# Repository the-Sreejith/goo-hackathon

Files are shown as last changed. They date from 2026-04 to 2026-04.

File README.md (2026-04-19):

# DummE

A small robotic arm on a rotating chassis. Sees its surroundings, understands a natural-language command **in any of 147 languages**, and executes it — all running on-device on a Raspberry Pi 5 using **Gemma 3n E2B**.

> User: *"pick up the red block and put it in the blue cup"* · *"लाल ब्लॉक उठाओ"* · *"أحضر المكعب الأحمر"*
> DummE: sweeps with the camera, finds red, picks it, rotates to blue, drops it in, goes home.

Zero cloud, zero latency, zero privacy compromise — with first-language access built in.

We prototyped the frame in cardboard (it was fragile; see `docs/submission.md` §6). Printable SG90-arm parts now live under `3d-models/` for a sturdier rebuild on the same electronics + software stack.

## Quickstart (MacBook dev)

```bash
git clone https://github.com/the-Sreejith/goo-hackathon
cd goo-hackathon
python3.13 -m venv .venv
source .venv/bin/activate
pip install -r requirements.txt
pip install -e ".[dev]"        # ruff, black, pytest, pytest-cov, httpx
cp .env.example .env

# Smoke test — canonical "pick red, put blue" end-to-end with mocks
python -m scripts.demo_run

# Run the web UI
DUMME_MOCK_HARDWARE=true uvicorn dumme.app:app --reload
# Open http://127.0.0.1:8000
```

Pi-only deps (`picamera2`, `adafruit-circuitpython-pca9685`, `piper-tts`, `vosk`) skip on macOS/x86_64 via platform markers. `DUMME_MOCK_HARDWARE=auto` detects the platform; force with `true`/`false`.

## Pi deployment

Follow [`docs/pi_setup.md`](./docs/pi_setup.md) top-to-bottom for OS flash, WiFi, I2C/SPI, llama.cpp build, and Gemma download. Then from the Mac:

```bash
# Sync code to the Pi (faster than git-on-Pi setup for a hackathon).
rsync -az --exclude '.venv' --exclude '.git' --exclude 'models/*.gguf' \
      --exclude '__pycache__' --exclude '.env' --exclude 'pi-passwords.txt' \
      ./ dumme@dumme.local:/home/dumme/dumme/
```

Install + start the systemd services once:

```bash
ssh dumme@dumme.local '
  sudo cp ~/dumme/systemd/dumme-llama.service /etc/systemd/system/
  sudo cp ~/dumme/systemd/dumme-app.service   /etc/systemd/system/
  sudo systemctl daemon-reload
  sudo systemctl enable --now dumme-llama.service dumme-app.service
'
```

UI lands on `http://dumme.local:8000`, LLM on `http://dumme.local:8080`.

## Voice commands (on-device STT)

DummE can take spoken commands instead of typed ones, transcribed offline by [Vosk](https://alphacephei.com/vosk/) — same privacy guarantees as the rest of the stack.

**Setup:**

```bash
pip install -r requirements.txt
# macOS dev: brew install portaudio
# Pi:        sudo apt install -y libportaudio2

# Download the small English model (~40 MB) into ./models/
curl -LO https://alphacephei.com/vosk/models/vosk-model-small-en-us-0.15.zip
unzip vosk-model-small-en-us-0.15.zip -d models/
mv models/vosk-model-small-en-us-0.15 models/vosk-model-small-en-us
```

Override the default model location with `DUMME_VOSK_MODEL=/path/to/model`.

**Use it:** click the 🎤 Speak button in the browser UI and talk for up to 5 seconds — the transcript populates the input and is sent through the same LLM → orchestrator pipeline as a typed command.

**API:** `POST /listen {"max_seconds": 5.0}` → `{"ok": bool, "message": str, "transcript": str}`.

**Mock mode** (no mic, no model — useful on the dev MacBook):

```bash
DUMME_MOCK_HARDWARE=true DUMME_MOCK_UTTERANCE="pick up the red block" \
    uvicorn dumme.app:app --reload
```

## Tests

```bash
make test            # unit + integration (default — hermetic, ~1 s)
make eval            # live LLM utterance eval (needs llama-server)
make smoke           # scripts/preflight.sh — run on the Pi before demo
make coverage        # pytest --cov with 80% floor
pytest -m hardware   # on the Pi only
```

See [`docs/testing.md`](./docs/testing.md) for the full tier breakdown and eval-report artifact format.

## Docs

| Topic | File |
|---|---|
| Hackathon brief + inventory | [`docs/starting_point.md`](./docs/starting_point.md) |
| Day-of build plan | [`docs/plan.md`](./docs/plan.md) |
| Pi setup (OS, WiFi, llama.cpp, Gemma) | [`docs/pi_setup.md`](./docs/pi_setup.md) |
| Module map + request trace | [`docs/architecture.md`](./docs/architecture.md) |
| GPIO / power / servo wiring | [`docs/wiring.md`](./docs/wiring.md) |
| Test tiers + eval report + CI | [`docs/testing.md`](./docs/testing.md) |
| Demo runbook (pre-flight + 90 s pitch) | [`docs/demo_script.md`](./docs/demo_script.md) |

Index: [`docs/README.md`](./docs/README.md).

## Project layout

```
dumme/          FastAPI app + modules (motion, vision, llm, calibration, io, utils)
config/         YAML configs + Gemma prompt template
static/         Browser UI (HTML + JS + CSS)
scripts/        Hardware smoke tests + preflight.sh + calibration + demo run
tests/          unit + integration + eval + hardware tiers
systemd/        dumme-llama.service + dumme-app.service
docs/           All setup / architecture / testing / demo / submission docs
models/         Gitignored .gguf files (Gemma weights, ~2.8 GB)
3d-models/      Printable SG90 arm + gripper parts (STL / 3MF / Fusion360)
.github/        CI workflow (ruff + black + pytest + coverage upload)
```

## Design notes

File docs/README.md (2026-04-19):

# DummE Docs

One entry per topic. Read `plan.md` and `pi_setup.md` first — every other
doc assumes you've done those.

## Start here

- [starting_point.md](./starting_point.md) — hackathon brief, inventory, prize criteria, final project pitch
- [plan.md](./plan.md) — day-of build plan: MVP slice, roles, schedule, cut list
- [pi_setup.md](./pi_setup.md) — shopping list, headless Pi flash, WiFi, llama.cpp build, Gemma download, systemd services

## Reference (during the build)

- [architecture.md](./architecture.md) — module map, request trace, hardware–software contract
- [wiring.md](./wiring.md) — GPIO pinout, power rails, kill switch, camera, servo channel map
- [testing.md](./testing.md) — test tiers, markers, eval harness, preflight script, coverage gate
- [demo_script.md](./demo_script.md) — pre-demo checklist, 90-second pitch, on-stage recovery
- [submission.md](./submission.md) — hackathon submission write-up (copy-paste into Google Docs)

## Hardware / code map

| Where | What |
|---|---|
| `dumme/app.py` | FastAPI entrypoint, `Services` container, lifespan |
| `dumme/orchestrator.py` | Command → action pipeline (the only module that knows the shape) |
| `dumme/llm/` | Gemma client + JSON-schema-constrained parser |
| `dumme/vision/` | OpenCV USB-camera capture + HSV blob detector |
| `dumme/motion/` | PCA9685 driver + Motion primitives + Safety clamps |
| `dumme/calibration/` | Pixel → (r, θ) affine regression |
| `dumme/io/` | Piper TTS + Vosk STT |
| `config/` | YAML configs + Gemma prompt template |
| `scripts/` | Hardware smoke utilities + `preflight.sh` + prompt eval |
| `tests/` | Unit + integration + eval + hardware tiers |
| `systemd/` | `dumme-llama.service`, `dumme-app.service` |
| `3d-models/` | Printable SG90 arm + gripper parts (STL / 3MF / Fusion 360) |

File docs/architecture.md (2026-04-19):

# DummE — Architecture

```
┌────────────────────────────────────────────────────────────┐
│                      Browser (any device)                   │
│              Text input + live camera MJPEG                 │
└────────────────────────────┬───────────────────────────────┘
                             │ HTTP
┌────────────────────────────▼───────────────────────────────┐
│                   FastAPI app (dumme/app.py)                │
│  POST /command   GET /stream   GET /status   POST /estop    │
└──┬────────────────┬────────────────┬───────────────────────┘
   │                │                │
┌──▼────────┐  ┌────▼─────┐   ┌──────▼──────────┐
│  llm/     │  │ vision/  │   │  orchestrator   │
│ Gemma 3n  │  │ cv2 UVC  │   │  Sweep → detect │
│ JSON-only │  │ + HSV    │   │  → pick → place │
└───────────┘  └──────────┘   └──────┬──────────┘
                                     │
                              ┌──────▼──────┐
                              │  motion/    │
                              │  PCA9685 +  │
                              │  primitives │
                              └──────┬──────┘
                                     │ I2C
                              ┌──────▼──────┐
                              │  PCA9685    │
                              │  → 5 servos │
                              └─────────────┘
```

## Module Responsibilities

### `dumme.app` — FastAPI entrypoint
Builds the `Services` container at startup (reads `config/*.yaml`), wires routes, serves `static/`. Every request handler delegates into `Orchestrator`, `LLM`, `Motion`, or `Camera` — no business logic lives in route handlers.

### `dumme.orchestrator` — The Command → Action loop
The only module that knows the pipeline shape. `execute(cmd)` dispatches `home` / `pick_and_place` / `unknown`. `sweep_and_detect(color)` iterates the turntable in 15° steps, calling `vision.find(color)` at each stop until a hit (or the full sweep completes).

### `dumme.motion/` — Hardware actuation
- `driver.PCA9685Driver` — microsecond-level PWM writes, lazy-imports `adafruit_pca9685` so this module loads on a MacBook.
- `primitives.Motion` — verbs the orchestrator calls (`home`, `pick`, `place`, `release_all`, `estop`). Every write goes through `Safety.clamp` and honours `Safety.estop`.
- `safety.Safety` — joint-limit clamping + thread-safe `EstopFlag`.

### `dumme.vision/` — Perception
- `camera.Camera` — `cv2.VideoCapture(0, cv2.CAP_V4L2)` wrapper for USB UVC webcams. One-shot + MJPEG generator. Falls back to solid-colour frames in mock mode.
- `detector.Vision` — HSV masking + morphology + contour selection. Returns `Detection(color, pixel_xy, area_px)` or `None`. Red hue wraps, so the config OR's two ranges together.

### `dumme.llm/` — Utterance → Command
- `client.LlamaClient` — HTTP client for local llama.cpp server on port 8080.
- `parser.LLM` — fills the prompt template, extracts JSON, validates, retries once. Falls back to `Command("unknown", ...)`.
- `schema` — `Command`, `ExecutionResult` dataclasses + `ok()`/`fail()` helpers.
- **Multilingual**: Gemma 3n covers 147 languages. The prompt template + JSON schema are language-agnostic — the same `Command("pick_and_place", "red", "blue")` comes out whether the user said "pick the red one" or "लाल ब्लॉक उठाओ". No per-locale build.

### `dumme.calibration/` — Pixel → polar (r, θ)
Affine regression fit from 5+ hand-captured samples. Used by the orchestrator to turn a detected pixel into a motion target.

### `dumme.io/` — Speech I/O
- `tts.TTS` — Piper wrapper for spoken replies.
- `mic.Mic` — Vosk STT, stretch only.

### `dumme.utils/` — Shared infrastructure
- `config.load_yaml` — reads `config/*.yaml`, resolves `DUMME_CONFIG_DIR` override.
- `logging.get_logger` — structured logging, respects `LOG_LEVEL`.

## Request Trace: `POST /command`

```
POST /command {"utterance": "pick red, drop blue"}
  → app.post_command
  → services.llm.parse(utterance)                 # HTTP → llama-server → JSON → Command
  → services.orchestrator.execute(cmd)
    → motion.base_rotate / turntable_rotate       # sweep
    → vision.find(target_color) ... (repeat)
    → calibration.pixel_to_polar(...)
    → motion.pick(r, θ)
    → (same for destination)
    → motion.place(r, θ); motion.home()
  → return ExecutionResult → JSON
```

## Hardware-Software Contract

| Concern | Boundary |
|---|---|
| PCA9685 I2C address | `0x40` (default) — `config/servos.yaml` is source of truth for channels |
| Servo pulse range | `min_us` / `max_us` per joint in `config/servos.yaml` |
| Joint soft limits | `joint_limits` in `config/servos.yaml` — enforced by `Safety.clamp` |
| Gemma backend | `http://127.0.0.1:8080/completion` — override via `LLAMA_URL` env. Current weights: `gemma-3n-E2B-it-Q4_K_M.gguf` (~2.8 GB). |
| Camera device | `/dev/video0` via OpenCV V4L2 (USB UVC). `picamera2` is supported if you wire a CSI ribbon and swap `Camera._open`. |

## Testing Strategy

See [testing.md](./testing.md) for the full breakdown. In short:

- **Unit** (`@pytest.mark.unit`, default) — hermetic logic: JSON extraction, regression math, safety clamps, motion pulse math, vision HSV, orchestrator dispatch with fakes, LLM client with mocked `requests`.
- **Integration** (`@pytest.mark.integration`, default) — FastAPI `TestClient` with a stubbed LLM.
- **Eval** (`@pytest.mark.eval`, opt-in) — live-LLM accuracy suite parametrized over 20 canonical utterances in `scripts/prompt_test.py::CASES`.
- **Hardware** (`@pytest.mark.hardware`, opt-in) — Pi-only: I2C ack at 0x40, camera frame variance, llama-server roundtrip.
- **Preflight** (`scripts/preflight.sh`) — 5-minute shell sanity check before demo.

The default `pytest` / `make test` run covers unit+integration; `make eval`, `pytest -m hardware`, and `make smoke` are the opt-in tiers.

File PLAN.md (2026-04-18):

# DummE — Physical AI Hackathon 2026 Build Plan

> **Goal**: A cardboard robotic arm on a rotating chassis that sees its surroundings, understands a natural-language command, and executes it — all running on-device on a Raspberry Pi 5 using Gemma.
>
> **Team**: 3 people. **Time**: 1 day. **Track**: Open Challenge / Accessibility (indoor assistance aide).

---

## 1. The MVP Demo

**Storyboard (90 seconds, the whole pitch):**

1. User opens the web UI and types or speaks: *"Pick up the red block and put it in the blue cup."*
2. DummE's chassis **rotates slowly**, sweeping the workspace with the camera.
3. When the red block enters the frame, DummE **stops** and says (TTS): *"Found the red block."*
4. The arm **picks** the block, the chassis **rotates** toward the blue cup, and the arm **drops** it in.
5. DummE returns to home pose and says: *"Task complete."*

That is the entire demo. Every feature not on this list is cut.

---

## 2. Hardware

### 2.1 BOM (from provided inventory)

| Part | Role | Qty |
|---|---|---|
| Raspberry Pi 5 (4GB) | Brain — vision, LLM, orchestration | 1 |
| Pi Camera Module | Perception | 1 |
| PCA9685 16-ch PWM Driver | Drives all servos over I2C | 1 |
| SG90 Micro Servo | Arm joints: base-rotate, shoulder, elbow, gripper | 4 |
| **MG90S Micro Servo** | **Chassis turntable** (holds the whole arm) | 1 |
| HC-SR04 Ultrasonic | Workspace safety stop (optional) | 1 |
| 5V/5A USB-C PSU | Pi power | 1 |
| 5–6V/3A battery or PSU | Servo power (separate rail) | 1 |

**Not used** (stay on the table for the hero photo): ESP32, Arduino Uno, remaining MG995s, GPS, DHT, BME, HX711, MPU6050, IR sensor.

### 2.2 Power Rules (critical)

- **Pi on its own USB-C 5V/5A.**
- **Servos on a separate 5–6V/3A rail.** Never power servos from the Pi's 5V pin — they'll brown out the CPU.
- **Common ground only** between the two rails.
- **Physical kill switch** (toggle or inline button) on the servo V+ line. You will need it.

### 2.3 Mechanical

**Arm (4-DOF, SG90s):**

| Joint | Servo | Range |
|---|---|---|
| J1 — base rotate | SG90 #1 | 0–180° |
| J2 — shoulder | SG90 #2 | 30–150° |
| J3 — elbow | SG90 #3 | 20–160° |
| J4 — gripper | SG90 #4 | open/close |

**Chassis turntable:** MG90S mounted below two cardboard discs. A skewer or dowel pin runs through the center of both discs as the rotation axis. A plastic lid or 3D-printed washer sits between them for low friction. The arm's base plate is glued to the top disc.

### 2.4 Cardboard Assembly Rules

SG90s are forgiving on cardboard (low torque), but these rules still matter:

- **Double-layer corrugated**, grain directions crossed, hot-glued.
- **Bamboo skewers or chopsticks** as internal bracing along every arm segment.
- **Servo horns**: sandwich the horn between the cardboard and a second small cardboard plate + washer. Screws pull through a single layer.
- **Keep arm segments short** (<15 cm each). Long segments amplify torque and cause sag.
- **Heavy base**: tape the chassis base to a book, a hardcover, or a box weighted with anything dense. A top-heavy arm will tip during a swing.
- **Cable routing**: run servo wires through the turntable's center pin area, leave slack so rotation doesn't yank them.

### 2.5 Payload Budget

SG90 torque ≈ 1.8 kg·cm. With a 10 cm forearm, payload at the gripper tip is roughly **100–150 g max**. Safe target objects:

- Ping-pong ball
- Foam cube (3 cm)
- Bottle cap
- Small plastic block

Avoid anything heavier than a matchbox.

---

## 3. Software Architecture

```
┌────────────────────────────────────────────────────────────┐
│                      Browser (any device)                   │
│              Text input + live camera MJPEG                 │
└────────────────────────────┬───────────────────────────────┘
                             │ HTTP
┌────────────────────────────▼───────────────────────────────┐
│                   FastAPI app (app.py)                      │
│  POST /command   GET /stream   GET /status   POST /estop   │
└──┬────────────────┬────────────────┬───────────────────────┘
   │                │                │
┌──▼────────┐  ┌────▼─────┐   ┌──────▼──────────┐
│  llm.py   │  │ vision.py│   │  orchestrator.py│
│ Gemma +   │  │ picamera2│   │  Sweep → detect │
│ JSON-only │  │ + HSV    │   │  → pick → place │
└───────────┘  └──────────┘   └──────┬──────────┘
                                     │
                              ┌──────▼──────┐
                              │  motion.py  │
                              │  PCA9685 +  │
                              │  primitives │
                              └──────┬──────┘
                                     │ I2C
                              ┌──────▼──────┐
                              │  PCA9685    │
                              │  → 5 servos │
                              └─────────────┘
```

### 3.1 Repo Layout

```
dumme/
├── app.py                  # FastAPI entrypoint, serves UI
├── config.yaml             # servo limits, HSV ranges, calibration
├── dumme/
│   ├── __init__.py
│   ├── motion.py           # PCA9685 driver, motion primitives
│   ├── vision.py           # picamera2 + HSV detection
│   ├── llm.py              # Gemma wrapper, JSON-strict prompt
│   ├── calibration.py      # pixel → (r, θ) map
│   └── orchestrator.py     # main command loop
├── static/
│   └── index.html          # single-file browser UI
├── models/
│   └── gemma-4-e2b-it-Q4_K_M.gguf   # primary model (fallback: gemma-3n-E2B-Q4)
├── scripts/
│   ├── servo_sweep.py      # sanity-check each servo
│   ├── calibrate.py        # interactive calibration ritual
│   └── test_pipeline.py    # scripted end-to-end demo
├── requirements.txt
└── README.md
```

### 3.2 Key Interfaces

**`motion.py`**
```python
class Motion:
    def home(self) -> None: ...
    def base_rotate(self, angle_deg: float) -> None: ...
    def pick(self, r_mm: float, theta_deg: float) -> None: ...
    def place(self, r_mm: float, theta_deg: float) -> None: ...
    def release_all(self) -> None: ...    # zero PWM, stops jitter
    def estop(self) -> None: ...          # freeze + cut power flag
```

**`vision.py`**
```python
@dataclass(frozen=True)
class Detection:
    color: str
    pixel_xy: tuple[int, int]
    area_px: int

class Vision:
    def frame(self) -> np.ndarray: ...
    def find(self, color: str) -> Detection | None: ...
```

**`llm.py`**
```python
@dataclass(frozen=True)
class Command:
    action: str                  # "pick_and_place" | "home" | "unknown"
    target_color: str | None
    dest_color: str | None

class LLM:
    def parse(self, utterance: str) -> Command: ...
```

**`orchestrator.py`**
```python
class Orchestrator:
    def execute(self, cmd: Command) -> ExecutionResult: ...
```

### 3.3 Gemma Model Choice

**Primary: Gemma 4 E2B (Q4_K_M GGUF)** — released April 2, 2026, first-party fit for the prize criteria.

| Aspect | Value |
|---|---|
| Model file | `gemma-4-e2b-it-Q4_K_M.gguf` (~1.6 GB) |
| Effective params | ~2.3B |
| Multimodal | Text + image + video in (we use text only) |
| Throughput on 4GB Pi 5 | ~2–6 tokens/sec (enough for ~30-token JSON) |
| Context cap | `--ctx-size 2048` (native 128K is too much KV cache for 4GB) |

**Fallback: Gemma 3n E2B Q4** — swap in if Gemma 4 E2B misbehaves under time pressure.

**Do NOT use on this Pi**: Gemma 4 E4B (~3GB, no RAM headroom), 26B MoE, 31B Dense.

**llama.cpp launch command**:
```bash
llama-server \
  -m models/gemma-4-e2b-it-Q4_K_M.gguf \
  --ctx-size 2048 \
  --n-predict 128 \
  --threads 4 \
  --host 127.0.0.1 --port 8080
```

### 3.4 Gemma Prompt (JSON-strict)

System prompt enforces the schema. Few-shot examples cover common phrasings. Retry once if output isn't valid JSON.

```
You are DummE's command parser. Convert the user's request to JSON ONLY.
Do not add commentary. Do not use markdown fences.

Schema:
{
  "action": "pick_and_place" | "home" | "unknown",
  "target_color": "red" | "blue" | "green" | null,
  "dest_color":   "red" | "blue" | "green" | null
}

Examples:
User: "pick up the red block and put it in the blue cup"
{"action":"pick_and_place","target_color":"red","dest_color":"blue"}

User: "grab the green one and drop it in red"
{"action":"pick_and_place","target_color":"green","dest_color":"red"}

User: "go home"
{"action":"home","target_color":null,"dest_color":null}

User: "dance for me"
{"action":"unknown","target_color":null,"dest_color":null}
```

### 3.5 Main Loop (pseudocode)

```python
def execute(cmd: Command) -> ExecutionResult:
    if cmd.action == "home":
        motion.home(); return ok()
    if cmd.action == "unknown":
        return fail("I didn't understand that.")

    # Sweep to find target
    target_hit = sweep_and_detect(cmd.target_color)
    if not target_hit:
        return fail(f"I can't see the {cmd.target_color} object.")

    # Pick
    r, theta = calibration.pixel_to_polar(target_hit.pixel_xy, motion.base_angle)
    motion.pick(r, theta)

    # Find destination
    dest_hit = sweep_and_detect(cmd.dest_color)
    if not dest_hit:
        motion.home(); return fail(f"I can't see the {cmd.dest_color} destination.")

    # Place
    r2, theta2 = calibration.pixel_to_polar(dest_hit.pixel_xy, motion.base_angle)
    motion.place(r2, theta2)
    motion.home()
    return ok()
```

---

## 4. Team Split

| Person | Track | Owns |
|---|---|---|
| **P1** | Hardware | Cardboard cut + assembly, servo mounting, PCA9685 wiring, power rails, kill switch |
| **P2** | Perception + LLM | `vision.py`, `llm.py`, Gemma setup, browser UI, live camera feed |
| **P3** | Motion + Integration | `motion.py`, `calibration.py`, `orchestrator.py`, `app.py`, demo script |

**Golden rule**: everyone commits a working stub to `main` in the first hour. No one waits on anyone.

---

## 5. Phased Execution

### Phase A — End-to-end skeleton (parallel, ~1 hour)

All three people land code on `main` **before any real hardware works**.

**P1 (Hardware)**
- Cut cardboard from the blueprint.
- Dry-fit arm + turntable (no glue yet).
- Label every servo wire (J1/J2/J3/J4/TURN).
- Solder power rail.

**P2 (Perception + LLM)**
- `vision.find()` returns a hardcoded fake `Detection` for any color.
- `llm.parse()` returns a hardcoded `Command` for one test string.
- Minimal HTML page: text box + Submit button + `<img src="/stream">`.

**P3 (Motion + Integration)**
- `motion.*` methods `print()` what they would do, no hardware calls.
- FastAPI app with `/command`, `/stream`, `/status`, `/estop`.
- `orchestrator.execute()` glues the three stubs.

**Exit gate**: typing "pick red, put blue" in the browser prints the full pipeline trace to the console. Nothing real works yet — that's fine.

### Phase B — Swap stubs for reality (parallel, ~3 hours)

**P1 (Hardware)**
- Final glue-up of arm and turntable.
- Mount Pi, camera, and PCA9685 on the chassis.
- Weight the base. Confirm turntable holds the arm without creep.
- Join P3 during calibration (hour ~4).

**P2 (Perception + LLM)**
1. `picamera2` live capture → Flask MJPEG stream at `/stream`.
2. HSV color masks for red, blue, green. Tune under the actual demo lighting.
3. `Vision.find(color)` returns the largest contour's centroid + area. Reject detections with area < threshold.
4. Install `llama.cpp` on Pi. Download **Gemma 4 E2B Q4_K_M GGUF** (~1.6 GB) to `models/`. Keep Gemma 3n E2B Q4 as a pre-downloaded fallback on disk.
5. Launch `llama-server` with `--ctx-size 2048 --threads 4`. Wire `LLM.parse()` to hit it over HTTP with the JSON-strict prompt.
6. Test **20+ phrasings**. Add few-shot examples until ≥95% parse correctly.
7. Add `piper` TTS for spoken replies.

**P3 (Motion + Integration)**
1. `Motion` class wraps `adafruit_pca9685`. Every servo has `min_us`, `max_us`, `home_deg` in `config.yaml`.
2. `scripts/servo_sweep.py` — sanity-check each servo individually.
3. **Calibration ritual** (run WITH the real arm, not simulated):
   - Place a block at 5 known `(x, y)` positions on the workspace.
   - For each: manually jog the arm to a good pick pose, record `(base_angle, shoulder, elbow)` and the pixel location of the block in the camera frame at turntable angle 0.
   - Fit a regression: `(pixel_x, pixel_y) → (shoulder, elbow)`. Linear or affine is fine.
   - Turntable rotation adds a constant offset: `absolute_theta = pixel_theta + turntable_angle`.
4. Primitives: `home()`, `base_rotate()`, `pick(r, theta)`, `place(r, theta)`, `release_all()`, `estop()`.
5. `sweep_and_detect(color)` — rotate turntable in 15° steps from -60° to +60°, capture frame at each stop, return first hit.

### Phase C — Integration + demo hardening (~2 hours)

- Run the full loop **10 times**. Each failure → a guard rail or a demo-script workaround.
- Common fixes you'll add:
  - Servo jitter at rest → `release_all()` after every primitive.
  - Block outside reach → polite TTS error + return to home.
  - Gripper slips the ball → slow down the lift; add a foam pad on the gripper tips.
  - Turntable slips → bigger servo horn contact area, more glue.
- **Record the demo video now.** Do not leave it for the last 15 minutes.
- Write the README with architecture diagram, Gemma callout, wiring photos.

### Phase D — Stretch goals (only if green by hour 7)

- Voice input via Vosk tiny (offline STT).
- A third color / object class.
- OLED status display over I2C.
- Ultrasonic e-stop: if HC-SR04 reads <20cm (human hand in workspace), freeze the arm.
- `sweep_and_detect` early-stop animation (rotate toward the target smoothly).

---

## 6. Hard Cuts (confirmed)

- ❌ 6-DOF arm — 4 is enough.
- ❌ Real inverse kinematics — regression from calibration points suffices.
- ❌ Wrist pitch/roll — gripper approaches vertically.
- ❌ Wheeled mobility — the chassis rotates but doesn't drive.
- ❌ Depth camera / stereo — workspace is a flat table at a known height.
- ❌ ESP32 / Arduino — Pi drives PCA9685 directly over I2C.
- ❌ Cloud LLM — Gemma on-device is the prize story.
- ❌ GPS, DHT, BME, HX711, MPU, IR — out of scope for the MVP.

---

## 7. Risk Register

| Risk | Likelihood | Mitigation |
|---|---|---|
| Arm tips forward when reaching | High | Heavy base (tape book/board under chassis) |
| SG90 jitter at rest | High | `release_all()` (PWM=0) after each motion |
| SG90s overheat during calibration | Medium | Short bursts; arm rests on cardboard support in home pose |
| Gemma returns malformed JSON | Medium | Strict schema prompt + 1-retry with reminder; regex extract `{...}` |
| Gemma 4 E2B hits RAM limit on 4GB Pi | Medium | Fall back to Gemma 3n E2B Q4 (pre-downloaded); drop `--ctx-size` to 1024 |
| Gemma token throughput too slow | Medium | Show "Thinking…" in UI; keep prompt short; cap `--n-predict 128` |
| HSV mask misses block under shadow | High | White sheet as workspace + desk lamp for even lighting |
| Cable pulled during base rotation | Medium | Route through turntable center; leave slack loop |
| Turntable slips under load | Medium | MG90S horn glued AND screwed; short arm segments |
| Pi CPU overload (vision + LLM) | Medium | Detect and LLM don't run concurrently; Gemma Q4 quantization |
| Gripper drops the ball | High | Foam pads on gripper tips; slow lift speed |
| Demo ambient light changes | Medium | Recalibrate HSV just before demo; add a lamp |

---

## 8. Prize Criteria Fit

- **Gemma 4**: we run **Gemma 4 E2B** (released April 2, 2026) **on-device** via `llama.cpp` on a 4GB Pi 5. First-party alignment with the prize's Gemma 4 preference — no cloud inference, no API calls, structured JSON output driving real-world actuation.
- **GCP ($5 budget)**: use Vertex AI only as an optional fallback for commands Gemma 4 can't parse, and cache aggressively. An on-device-only story is simpler and probably more compelling — lean on "zero cloud, zero latency, zero privacy compromise" as the narrative.
- **Physical AI**: camera + servos + cardboard form factor + real-world pick-and-place.
- **Track fit** (Accessibility or Open): voice/text command → physical action maps directly to "empowering people with disabilities" or "open-ended AI + hardware".

---

## 9. Pre-flight Checklist

**Hardware, OS, and model setup are documented in [`PI_SETUP.md`](./PI_SETUP.md).** Complete every step (including the verification checklist in §9 of that doc) **before** hack day starts.

**Project-specific readiness** (additional to `PI_SETUP.md`):
- [ ] Repo scaffold (`app.py`, `motion.py`, `vision.py`, `llm.py`, `config.yaml`, `scripts/`) pushed to GitHub.
- [ ] Cardboard blueprints printed.
- [ ] Props on hand: cardboard sheets, hot glue, skewers, foam cubes, ping-pong ball, coloured cups, desk lamp, white workspace backdrop.
- [ ] 1–2 extra SG90 servos (burnout insurance).
- [ ] Kill switch wired inline on servo V+ and physically tested (multimeter-verified).

---

## 10. One-Page Demo Day Runbook

1. **30 min before**: power up, run `scripts/test_pipeline.py`, recalibrate HSV under demo lighting.
2. **10 min before**: home pose, release servos, close unused apps on the Pi.
3. **Demo**:
   - Show the cardboard arm (authenticity wins hearts).
   - Open the browser UI on a phone or laptop.
   - Type the command. Let Gemma parse (show the JSON on screen).
   - Watch the sweep, pick, place, return home.
   - Final line: *"Everything you saw ran on the Pi. No cloud."*
4. **Backup**: if live run fails, play the pre-recorded video immediately. Do not freeze.

---

**Ready to scaffold the repo?** Once the plan is approved, create the directory tree in §3.1 and commit working stubs so P1/P2/P3 can start in parallel.

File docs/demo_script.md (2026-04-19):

# DummE — Demo Day Runbook

## 30 min before

- [ ] Power up Pi + servo rail, open SSH from all 3 MacBooks.
- [ ] `bash scripts/preflight.sh` — green on all 5 checks. If not, fix now.
- [ ] `python -m scripts.servo_sweep` — each joint rotates through full range, no binding.
- [ ] `python -m scripts.prompt_test` — ≥ 18/20 pass. (Or `pytest -m eval` for the report artifact.)
- [ ] Recalibrate HSV: `python -m scripts.camera_preview` under the demo lighting, tweak `config/vision.yaml`.
- [ ] Confirm systemd services are running: `systemctl status dumme-llama.service dumme-app.service --no-pager`.
- [ ] Run `python -m scripts.demo_run` — result `ok=True`.

## 10 min before

- [ ] Motion to home pose; call `release_all()` so servos aren't jittering on stage.
- [ ] Close unused apps on the Pi (`pgrep -af python` — kill strays).
- [ ] White workspace backdrop laid out, desk lamp on.
- [ ] Target blocks + cups placed within reach envelope.
- [ ] Phone/laptop has `http://dumme.local:8000` open.
- [ ] **Backup video cued up** in case live run fails.

## The Demo (90 seconds)

1. **Introduce the arm** (10s) — "This is DummE. 100% cardboard. 4-DOF arm on a rotating chassis. The Pi 5 you see on the base runs Gemma 3n E2B locally — zero cloud."
2. **Open the UI** (5s) — show the camera feed, say what we're about to ask for.
3. **Type the command** (10s) — "pick up the red block and put it in the blue cup". (Optional wow beat: repeat it in a second language — *"लाल ब्लॉक उठाओ"* or the judge's first language — to show Gemma 3n's 147-language coverage in one device.)
4. **Gemma parses** (5s) — briefly show the returned JSON on screen. Mention: on-device, ~1–3 seconds at ~5 tok/s on CPU.
5. **Arm acts** (45s) — chassis sweeps, finds red, picks, rotates, drops in blue, returns home.
6. **Close the pitch** (15s) — "Everything you saw ran on the Pi. No cloud, no API calls, no network round-trip. That's the Gemma story at the edge."

## If the live run fails

Do not freeze. Say: *"Let me show you the run we recorded this morning — same code, same hardware."* Hit play on the backup video. The pitch continues.

## Common on-stage recovery

| Symptom | Quick fix |
|---|---|
| Arm doesn't move | Check kill switch; POST `/estop/clear`. |
| "I can't see the X object" | Move the block; adjust lamp; re-send. |
| Gripper drops the ball | Add a foam pad (cue in pocket); reduce lift speed in `config/servos.yaml`. |
| Servo jitter when idle | `release_all()` wasn't called — POST `/command {"utterance":"go home"}` then stop. |
| Camera feed black | Ribbon cable reversed. Flip it. (Pre-flight should catch this.) |

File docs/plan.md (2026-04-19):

# DummE — Physical AI Hackathon 2026 Build Plan

> **Goal**: A cardboard robotic arm on a rotating chassis that sees its surroundings, understands a natural-language command, and executes it — all running on-device on a Raspberry Pi 5 using Gemma.
>
> **Team**: 3 people. **Time**: 1 day. **Track**: Open Challenge / Accessibility (indoor assistance aide).

---

## 1. The MVP Demo

**Storyboard (90 seconds, the whole pitch):**

1. User opens the web UI and types or speaks: *"Pick up the red block and put it in the blue cup."*
2. DummE's chassis **rotates slowly**, sweeping the workspace with the camera.
3. When the red block enters the frame, DummE **stops** and says (TTS): *"Found the red block."*
4. The arm **picks** the block, the chassis **rotates** toward the blue cup, and the arm **drops** it in.
5. DummE returns to home pose and says: *"Task complete."*

That is the entire demo. Every feature not on this list is cut.

---

## 2. Hardware

### 2.1 BOM (from provided inventory)

| Part | Role | Qty |
|---|---|---|
| Raspberry Pi 5 (4GB) | Brain — vision, LLM, orchestration | 1 |
| Pi Camera Module | Perception | 1 |
| PCA9685 16-ch PWM Driver | Drives all servos over I2C | 1 |
| SG90 Micro Servo | Arm joints: base-rotate, shoulder, elbow, gripper | 4 |
| **MG90S Micro Servo** | **Chassis turntable** (holds the whole arm) | 1 |
| HC-SR04 Ultrasonic | Workspace safety stop (optional) | 1 |
| 5V/5A USB-C PSU | Pi power | 1 |
| 5–6V/3A battery or PSU | Servo power (separate rail) | 1 |

**Not used** (stay on the table for the hero photo): ESP32, Arduino Uno, remaining MG995s, GPS, DHT, BME, HX711, MPU6050, IR sensor.

### 2.2 Power Rules (critical)

- **Pi on its own USB-C 5V/5A.**
- **Servos on a separate 5–6V/3A rail.** Never power servos from the Pi's 5V pin — they'll brown out the CPU.
- **Common ground only** between the two rails.
- **Physical kill switch** (toggle or inline button) on the servo V+ line. You will need it.

### 2.3 Mechanical

**Arm (4-DOF, SG90s):**

| Joint | Servo | Range |
|---|---|---|
| J1 — base rotate | SG90 #1 | 0–180° |
| J2 — shoulder | SG90 #2 | 30–150° |
| J3 — elbow | SG90 #3 | 20–160° |
| J4 — gripper | SG90 #4 | open/close |

**Chassis turntable:** MG90S mounted below two cardboard discs. A skewer or dowel pin runs through the center of both discs as the rotation axis. A plastic lid or 3D-printed washer sits between them for low friction. The arm's base plate is glued to the top disc.

### 2.4 Cardboard Assembly Rules

SG90s are forgiving on cardboard (low torque), but these rules still matter:

- **Double-layer corrugated**, grain directions crossed, hot-glued.
- **Bamboo skewers or chopsticks** as internal bracing along every arm segment.
- **Servo horns**: sandwich the horn between the cardboard and a second small cardboard plate + washer. Screws pull through a single layer.
- **Keep arm segments short** (<15 cm each). Long segments amplify torque and cause sag.
- **Heavy base**: tape the chassis base to a book, a hardcover, or a box weighted with anything dense. A top-heavy arm will tip during a swing.
- **Cable routing**: run servo wires through the turntable's center pin area, leave slack so rotation doesn't yank them.

### 2.5 Payload Budget

SG90 torque ≈ 1.8 kg·cm. With a 10 cm forearm, payload at the gripper tip is roughly **100–150 g max**. Safe target objects:

- Ping-pong ball
- Foam cube (3 cm)
- Bottle cap
- Small plastic block

Avoid anything heavier than a matchbox.

---

## 3. Software Architecture

```
┌────────────────────────────────────────────────────────────┐
│                      Browser (any device)                   │
│              Text input + live camera MJPEG                 │
└────────────────────────────┬───────────────────────────────┘
                             │ HTTP
┌────────────────────────────▼───────────────────────────────┐
│                   FastAPI app (app.py)                      │
│  POST /command   GET /stream   GET /status   POST /estop   │
└──┬────────────────┬────────────────┬───────────────────────┘
   │                │                │
┌──▼────────┐  ┌────▼─────┐   ┌──────▼──────────┐
│  llm.py   │  │ vision.py│   │  orchestrator.py│
│ Gemma 3n  │  │ cv2 UVC  │   │  Sweep → detect │
│ JSON-only │  │ + HSV    │   │  → pick → place │
└───────────┘  └──────────┘   └──────┬──────────┘
                                     │
                              ┌──────▼──────┐
                              │  motion.py  │
                              │  PCA9685 +  │
                              │  primitives │
                              └──────┬──────┘
                                     │ I2C
                              ┌──────▼──────┐
                              │  PCA9685    │
                              │  → 5 servos │
                              └─────────────┘
```

### 3.1 Repo Layout

```
dumme/
├── app.py                  # FastAPI entrypoint, serves UI
├── config.yaml             # servo limits, HSV ranges, calibration
├── dumme/
│   ├── __init__.py
│   ├── motion.py           # PCA9685 driver, motion primitives
│   ├── vision.py           # OpenCV UVC + HSV detection
│   ├── llm.py              # Gemma wrapper, JSON-strict prompt
│   ├── calibration.py      # pixel → (r, θ) map
│   └── orchestrator.py     # main command loop
├── static/
│   └── index.html          # single-file browser UI
├── models/
│   └── gemma-3n-E2B-it-Q4_K_M.gguf  # active model (~2.8 GB)
├── scripts/
│   ├── servo_sweep.py      # sanity-check each servo
│   ├── calibrate.py        # interactive calibration ritual
│   └── test_pipeline.py    # scripted end-to-end demo
├── requirements.txt
└── README.md
```

### 3.2 Key Interfaces

**`motion.py`**
```python
class Motion:
    def home(self) -> None: ...
    def base_rotate(self, angle_deg: float) -> None: ...
    def pick(self, r_mm: float, theta_deg: float) -> None: ...
    def place(self, r_mm: float, theta_deg: float) -> None: ...
    def release_all(self) -> None: ...    # zero PWM, stops jitter
    def estop(self) -> None: ...          # freeze + cut power flag
```

**`vision.py`**
```python
@dataclass(frozen=True)
class Detection:
    color: str
    pixel_xy: tuple[int, int]
    area_px: int

class Vision:
    def frame(self) -> np.ndarray: ...
    def find(self, color: str) -> Detection | None: ...
```

**`llm.py`**
```python
@dataclass(frozen=True)
class Command:
    action: str                  # "pick_and_place" | "home" | "unknown"
    target_color: str | None
    dest_color: str | None

class LLM:
    def parse(self, utterance: str) -> Command: ...
```

**`orchestrator.py`**
```python
class Orchestrator:
    def execute(self, cmd: Command) -> ExecutionResult: ...
```

### 3.3 Gemma Model Choice

**Active: Gemma 3n E2B (Q4_K_M GGUF)** — edge-optimised, supported by llama.cpp, validated on Pi 5.

| Aspect | Value |
|---|---|
| Model file | `gemma-3n-E2B-it-Q4_K_M.gguf` (~2.8 GB; `unsloth` mirror) |
| Effective params | ~2 B |
| Multimodal | Text-only on our path |
| Throughput on 4GB Pi 5 | ~3–5 tokens/sec (plenty for a ~20-token JSON reply) |
| Context cap | `--ctx-size 2048` (native 128K is too much KV cache for 4GB) |

> The original plan targeted **Gemma 4 E2B** for first-party prize alignment, but that variant isn't available as a published GGUF on Hugging Face at build time. Gemma 3n E2B is the functionally equivalent replacement — same on-device Gemma story, shippable.

**Do NOT use on this Pi**: Gemma 3n E4B (~4 GB, no RAM headroom for app + OS), 26B MoE, 31B Dense.

**llama.cpp launch command** (or use `systemctl start dumme-llama.service`):
```bash
llama-server \
  -m models/gemma-3n-E2B-it-Q4_K_M.gguf \
  --ctx-size 2048 \
  --threads 4 \
  --host 127.0.0.1 --port 8080
```

### 3.4 Gemma Prompt (JSON-strict)

System prompt enforces the schema. Few-shot examples cover common phrasings. Retry once if output isn't valid JSON.

```
You are DummE's command parser. Convert the user's request to JSON ONLY.
Do not add commentary. Do not use markdown fences.

Schema:
{
  "action": "pick_and_place" | "home" | "unknown",
  "target_color": "red" | "blue" | "green" | null,
  "dest_color":   "red" | "blue" | "green" | null
}

Examples:
User: "pick up the red block and put it in the blue cup"
{"action":"pick_and_place","target_color":"red","dest_color":"blue"}

User: "grab the green one and drop it in red"
{"action":"pick_and_place","target_color":"green","dest_color":"red"}

User: "go home"
{"action":"home","target_color":null,"dest_color":null}

User: "dance for me"
{"action":"unknown","target_color":null,"dest_color":null}
```

### 3.5 Main Loop (pseudocode)

```python
def execute(cmd: Command) -> ExecutionResult:
    if cmd.action == "home":
        motion.home(); return ok()
    if cmd.action == "unknown":
        return fail("I didn't understand that.")

    # Sweep to find target
    target_hit = sweep_and_detect(cmd.target_color)
    if not target_hit:
        return fail(f"I can't see the {cmd.target_color} object.")

    # Pick
    r, theta = calibration.pixel_to_polar(target_hit.pixel_xy, motion.base_angle)
    motion.pick(r, theta)

    # Find destination
    dest_hit = sweep_and_detect(cmd.dest_color)
    if not dest_hit:
        motion.home(); return fail(f"I can't see the {cmd.dest_color} destination.")

    # Place
    r2, theta2 = calibration.pixel_to_polar(dest_hit.pixel_xy, motion.base_angle)
    motion.place(r2, theta2)
    motion.home()
    return ok()
```

---

## 4. Team Split

| Person | Track | Owns |
|---|---|---|
| **P1** | Hardware | Cardboard cut + assembly, servo mounting, PCA9685 wiring, power rails, kill switch |
| **P2** | Perception + LLM | `vision.py`, `llm.py`, Gemma setup, browser UI, live camera feed |
| **P3** | Motion + Integration | `motion.py`, `calibration.py`, `orchestrator.py`, `app.py`, demo script |

**Golden rule**: everyone commits a working stub to `main` in the first hour. No one waits on anyone.

---

## 5. Phased Execution

### Phase A — End-to-end skeleton (parallel, ~1 hour)

All three people land code on `main` **before any real hardware works**.

**P1 (Hardware)**
- Cut cardboard from the blueprint.
- Dry-fit arm + turntable (no glue yet).
- Label every servo wire (J1/J2/J3/J4/TURN).
- Solder power rail.

**P2 (Perception + LLM)**
- `vision.find()` returns a hardcoded fake `Detection` for any color.
- `llm.parse()` returns a hardcoded `Command` for one test string.
- Minimal HTML page: text box + Submit button + `<img src="/stream">`.

**P3 (Motion + Integration)**
- `motion.*` methods `print()` what they would do, no hardware calls.
- FastAPI app with `/command`, `/stream`, `/status`, `/estop`.
- `orchestrator.execute()` glues the three stubs.

**Exit gate**: typing "pick red, put blue" in the browser prints the full pipeline trace to the console. Nothing real works yet — that's fine.

### Phase B — Swap stubs for reality (parallel, ~3 hours)

**P1 (Hardware)**
- Final glue-up of arm and turntable.
- Mount Pi, camera, and PCA9685 on the chassis.
- Weight the base. Confirm turntable holds the arm without creep.
- Join P3 during calibration (hour ~4).

**P2 (Perception + LLM)**
1. `cv2.VideoCapture(0)` USB UVC capture → FastAPI MJPEG stream at `/stream` (swap in `picamera2` if using a CSI ribbon).
2. HSV color masks for red, blue, green. Tune under the actual demo lighting.
3. `Vision.find(color)` returns the largest contour's centroid + area. Reject detections with area < threshold.
4. Install `llama.cpp` on Pi. Download **Gemma 3n E2B Q4_K_M GGUF** (~2.8 GB, via `unsloth` on Hugging Face) to `models/`.
5. Launch `llama-server` with `--ctx-size 2048 --threads 4`. Wire `LLM.parse()` to hit it over HTTP with the JSON-strict prompt.
6. Test **20+ phrasings**. Add few-shot examples until ≥95% parse correctly.
7. Add `piper` TTS for spoken replies.

**P3 (Motion + Integration)**
1. `Motion` class wraps `adafruit_pca9685`. Every servo has `min_us`, `max_us`, `home_deg` in `config.yaml`.
2. `scripts/servo_sweep.py` — sanity-check each servo individually.
3. **Calibration ritual** (run WITH the real arm, not simulated):
   - Place a block at 5 known `(x, y)` positions on the workspace.
   - For each: manually jog the arm to a good pick pose, record `(base_angle, shoulder, elbow)` and the pixel location of the block in the camera frame at turntable angle 0.
   - Fit a regression: `(pixel_x, pixel_y) → (shoulder, elbow)`. Linear or affine is fine.
   - Turntable rotation adds a constant offset: `absolute_theta = pixel_theta + turntable_angle`.
4. Primitives: `home()`, `base_rotate()`, `pick(r, theta)`, `place(r, theta)`, `release_all()`, `estop()`.
5. `sweep_and_detect(color)` — rotate turntable in 15° steps from -60° to +60°, capture frame at each stop, return first hit.

### Phase C — Integration + demo hardening (~2 hours)

- Run the full loop **10 times**. Each failure → a guard rail or a demo-script workaround.
- Common fixes you'll add:
  - Servo jitter at rest → `release_all()` after every primitive.
  - Block outside reach → polite TTS error + return to home.
  - Gripper slips the ball → slow down the lift; add a foam pad on the gripper tips.
  - Turntable slips → bigger servo horn contact area, more glue.
- **Record the demo video now.** Do not leave it for the last 15 minutes.
- Write the README with architecture diagram, Gemma callout, wiring photos.

### Phase D — Stretch goals (only if green by hour 7)

- Voice input via Vosk tiny (offline STT).
- A third color / object class.
- OLED status display over I2C.
- Ultrasonic e-stop: if HC-SR04 reads <20cm (human hand in workspace), freeze the arm.
- `sweep_and_detect` early-stop animation (rotate toward the target smoothly).

---

## 6. Hard Cuts (confirmed)

- ❌ 6-DOF arm — 4 is enough.
- ❌ Real inverse kinematics — regression from calibration points suffices.
- ❌ Wrist pitch/roll — gripper approaches vertically.
- ❌ Wheeled mobility — the chassis rotates but doesn't drive.
- ❌ Depth camera / stereo — workspace is a flat table at a known height.
- ❌ ESP32 / Arduino — Pi drives PCA9685 directly over I2C.
- ❌ Cloud LLM — Gemma on-device is the prize story.
- ❌ GPS, DHT, BME, HX711, MPU, IR — out of scope for the MVP.

---

## 7. Risk Register

| Risk | Likelihood | Mitigation |
|---|---|---|
| Arm tips forward when reaching | High | Heavy base (tape book/board under chassis) |
| SG90 jitter at rest | High | `release_all()` (PWM=0) after each motion |
| SG90s overheat during calibration | Medium | Short bursts; arm rests on cardboard support in home pose |
| Gemma returns malformed JSON | Medium | Strict schema prompt + 1-retry with reminder; regex extract `{...}` |
| Gemma 3n E2B hits RAM limit on 4GB Pi | Medium | Drop `--ctx-size` to 1024; close unused services; check `free -h` |
| Gemma token throughput too slow | Medium | Show "Thinking…" in UI; keep prompt short; cap `--n-predict 128` |
| HSV mask misses block under shadow | High | White sheet as workspace + desk lamp for even lighting |
| Cable pulled during base rotation | Medium | Route through turntable center; leave slack loop |
| Turntable slips under load | Medium | MG90S horn glued AND screwed; short arm segments |
| Pi CPU overload (vision + LLM) | Medium | Detect and LLM don't run concurrently; Gemma Q4 quantization |
| Gripper drops the ball | High | Foam pads on gripper tips; slow lift speed |
| Demo ambient light changes | Medium | Recalibrate HSV just before demo; add a lamp |

---

## 8. Prize Criteria Fit

- **Gemma**: we run **Gemma 3n E2B** **on-device** via `llama.cpp` on a 4GB Pi 5. On-device Gemma, structured JSON output driving real-world actuation — no cloud, no API calls.
- **Accessibility / multilingual**: Gemma 3n supports **147 languages**, so the same device serves users across ages and first languages without a cloud translation hop. This is the headline accessibility story for the submission.
- **GCP ($5 budget)**: use Vertex AI only as an optional fallback for commands Gemma can't parse locally, and cache aggressively. An on-device-only story is simpler and probably more compelling — lean on "zero cloud, zero latency, zero privacy compromise" as the narrative.
- **Physical AI**: camera + servos + cardboard form factor + real-world pick-and-place.
- **Track fit** (Accessibility or Open): voice/text command → physical action maps directly to "empowering people with disabilities" or "open-ended AI + hardware".

---

## 9. Pre-flight Checklist

**Hardware, OS, and model setup are documented in [`pi_setup.md`](./pi_setup.md).** Complete every step (including the verification checklist in §10 of that doc) **before** hack day starts.

**Project-specific readiness** (additional to `pi_setup.md`):
- [ ] Repo scaffold (`app.py`, `motion.py`, `vision.py`, `llm.py`, `config.yaml`, `scripts/`) pushed to GitHub.
- [ ] Cardboard blueprints printed.
- [ ] Props on hand: cardboard sheets, hot glue, skewers, foam cubes, ping-pong ball, coloured cups, desk lamp, white workspace backdrop.
- [ ] 1–2 extra SG90 servos (burnout insurance).
- [ ] Kill switch wired inline on servo V+ and physically tested (multimeter-verified).

---

## 10. One-Page Demo Day Runbook

1. **30 min before**: power up, run `scripts/test_pipeline.py`, recalibrate HSV under demo lighting.
2. **10 min before**: home pose, release servos, close unused apps on the Pi.
3. **Demo**:
   - Show the cardboard arm (authenticity wins hearts).
   - Open the browser UI on a phone or laptop.
   - Type the command. Let Gemma parse (show the JSON on screen).
   - Watch the sweep, pick, place, return home.
   - Final line: *"Everything you saw ran on the Pi. No cloud."*
4. **Backup**: if live run fails, play the pre-recorded video immediately. Do not freeze.

---

**Ready to scaffold the repo?** Once the plan is approved, create the directory tree in §3.1 and commit working stubs so P1/P2/P3 can start in parallel.

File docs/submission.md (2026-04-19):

# DummE — Physical AI Hackathon 2026 Submission

**A cardboard robotic arm that understands natural language, running Gemma entirely on a Raspberry Pi 5. Zero cloud, zero latency, zero privacy compromise.**

- **Track**: Open Challenge / Accessibility
- **Team**: 3 builders, 1 day, ₹0 of budget on cloud
- **Repo**: https://github.com/the-Sreejith/goo-hackathon
- **Demo video**: _link here_
- **Status**: end-to-end working pipeline on real hardware with 76 passing tests, CI, and a 20-case LLM eval harness

---

## 1. The Problem

Most "AI + robotics" demos today either depend on a cloud LLM (latency, privacy, cost) or run a hard-coded script pretending to understand language. Neither is deployable in the places where a helping hand actually matters — a low-bandwidth clinic, an assistive device in a user's home, a field robot in a farm with spotty internet.

Accessibility makes this worse: the English-first assumption in most edge-AI assistive tech excludes the majority of the world. A person whose first language is Marathi, Bhojpuri, Tamil, Swahili, or Tagalog shouldn't need to learn English to ask a robot for help.

**The question we wanted to answer:** can a 4 GB Raspberry Pi — the cheapest, most widely-available single-board computer — run a *generative* language model (in the user's own language), a *perception* stack, and a *motion* stack, together, at a latency that feels alive?

**Answer:** yes. And the code fits on an SD card.

---

## 2. The Demo (90 seconds)

1. Open a browser pointed at `http://dumme.local:8000` — DummE's built-in web UI streams the camera live.
2. Type (or later, speak): *"pick up the red block and put it in the blue cup."*
3. Gemma 3n parses the utterance on-device into structured JSON:
   ```json
   {"action": "pick_and_place", "target_color": "red", "dest_color": "blue"}
   ```
4. The chassis starts rotating. The camera sweeps the workspace. When the red block enters the frame, DummE stops and says (via Piper TTS): *"Found the red block."*
5. The 4-DOF arm reaches down, closes its gripper, and lifts.
6. The chassis rotates toward the blue cup. The arm drops the block in.
7. DummE returns to home pose, says *"Task complete."*

Total elapsed time: about 25 seconds of action + ~3 seconds of thinking. No network requests leave the Pi.

---

## 3. What Makes This Submission Different

| Dimension | Why it matters |
|---|---|
| **Fully on-device** | Gemma 3n E2B runs via `llama.cpp` with `llama-server` as a local HTTP endpoint. The app talks to `127.0.0.1:8080`. Airplane mode does not break anything. |
| **Multilingual by default** | Gemma 3n understands **147 languages**. The same prompt template works whether the user says *"pick up the red block"*, *"लाल ब्लॉक उठाओ"*, or *"أحضر المكعب الأحمر"* — no per-language build, no translation hop, no cloud. This is the accessibility story: one device that meets users in their own language, across age groups and literacy levels. |
| **Physical, not simulated** | Real SG90 + MG90S servos, real PCA9685 over I2C, real USB webcam through V4L2. Not a Unity/Isaac sim. |
| **Structured grounding** | The LLM is constrained to emit a small JSON schema (`action`, `target_color`, `dest_color`). A JSON-extraction + retry + validation layer turns stochastic text into deterministic control — regardless of which language the user typed. |
| **Engineered, not just hacked** | 76 passing tests across 4 tiers, ≥80% unit coverage, CI on GitHub Actions, pre-commit hooks, a 20-utterance eval harness with per-case accuracy, and an on-device preflight script. See §8. |
| **Reproducible** | `docs/pi_setup.md` is a complete, validated headless-flash-to-running-demo recipe including the WPA3-to-WPA2 gotcha that cost us 30 minutes. |

---

## 4. How It Works — Architecture

```
┌────────────────────────────────────────────────────────────┐
│                      Browser (any device)                   │
│              Text input + live camera MJPEG                 │
└────────────────────────────┬───────────────────────────────┘
                             │ HTTP
┌────────────────────────────▼───────────────────────────────┐
│                   FastAPI app (dumme/app.py)                │
│  POST /command   GET /stream   GET /status   POST /estop    │
└──┬────────────────┬────────────────┬───────────────────────┘
   │                │                │
┌──▼────────┐  ┌────▼─────┐   ┌──────▼──────────┐
│  llm/     │  │ vision/  │   │  orchestrator   │
│ Gemma 3n  │  │ cv2 UVC  │   │  Sweep → detect │
│ JSON-only │  │ + HSV    │   │  → pick → place │
└───────────┘  └──────────┘   └──────┬──────────┘
                                     │
                              ┌──────▼──────┐
                              │  motion/    │
                              │  PCA9685 +  │
                              │  primitives │
                              └──────┬──────┘
                                     │ I2C
                              ┌──────▼──────┐
                              │  5 servos + │
                              │  kill switch│
                              └─────────────┘
```

**Request trace** for `POST /command`:

1. FastAPI hands the utterance to `LLM.parse`.
2. `LlamaClient.complete` POSTs the prompt (with 5 few-shot examples) to `llama-server`. Gemma returns text; we extract the first balanced `{...}` block, coerce it to a frozen `Command` dataclass, retry once with a reminder if it's malformed, and fall back to `Command("unknown", ...)` otherwise.
3. The `Orchestrator` dispatches on `cmd.action`. For `pick_and_place`, it sweeps the turntable in 15° steps, calling `Vision.find(color)` at each stop. On a hit, it asks the `Calibration` module for `(r_mm, θ_deg)`, checks reach, and calls `Motion.pick`.
4. `Motion` pushes each joint through `Safety.clamp` (configured soft limits), converts degrees → microseconds at the per-servo pulse range, and writes via the `PCA9685Driver` over I2C.
5. The pipeline repeats for the destination, places, returns home, releases PWM (stops SG90 jitter), and returns an `ExecutionResult` to the UI.

The code is organized so the orchestrator is the **only** module that knows the pipeline shape. Every other module is a pure, testable verb.

---

## 5. The Gemma Story

### What we use

- **Model**: `gemma-3n-E2B-it-Q4_K_M.gguf` (≈ 2.8 GB, Unsloth's Hugging Face mirror)
- **Language coverage**: **147 languages** out of the box — one model, one binary, every major language the user might speak. This is the single biggest accessibility lever: no per-locale build, no cloud translation fallback.
- **Runtime**: `llama.cpp`, built natively for aarch64 with `cmake -B build -DGGML_NATIVE=ON`
- **Host**: a `llama-server` systemd unit on the Pi, `127.0.0.1:8080`, auto-restart, `OOMScoreAdjust=500` so a runaway LLM gets killed before the app
- **Context**: `--ctx-size 2048` (enough for schema + prompt + reply; fits KV cache inside 4 GB)
- **Throughput**: ~3–5 tokens/sec on the Pi 5 4GB, active cooler, threads=4. First load mmap is ~30 s; subsequent replies complete in 1–3 s

### Why this is the interesting part

Raw generation isn't the trick — constraining the output is. Our prompt template (`config/prompts/command_parser.txt`) gives Gemma a 4-key schema and 5 few-shot examples. On the Pi side:

- `_extract_json` tolerates markdown fences, leading prose, and nested braces
- `_coerce_to_command` validates against `typing.get_args(Action)` and `Color` — unknown colors or typos become `None`
- One retry with a "REMINDER: JSON only" suffix catches the 1-in-20 case where Gemma chats first and JSONs later
- Final fallback is `Command("unknown", None, None)` — the orchestrator responds politely instead of crashing

### How we know it works

`tests/eval/test_utterance_parsing.py` parametrizes 20 canonical utterances — literal, paraphrased, mixed-case, underspecified, out-of-domain — and asserts each parses to the right `Command` against the live `llama-server`. The suite emits `eval_report.json`:

```json
{
  "summary": {"total": 20, "passed": 19, "accuracy": 0.95},
  "cases": [...]
}
```

This gives the team a regression signal whenever we edit the prompt.

---

## 6. Hardware

### BOM

| Part | Role |
|---|---|
| **Raspberry Pi 5 (4GB)** + 27W USB-C PSU + Active Cooler | Everything: vision, LLM, orchestrator, web UI |
| **USB UVC webcam** | Perception, surfaced at `/dev/video0`, 640×480 @ 15 fps via OpenCV V4L2 |
| **PCA9685 16-ch PWM Driver** | Arm + chassis servo control over I2C |
| **4× SG90 servos** | Base-rotate, shoulder, elbow, gripper |
| **1× MG90S servo** | Chassis turntable (rotates the whole arm relative to the floor) |
| **4× AA battery pack + SPST kill switch** | Separate servo power rail (mandatory — Pi 5V will brown out) |

### Mechanical: cardboard prototype → 3D-printed arm

We built the first prototype out of cardboard, hot glue, and bamboo skewers to validate the electronics end-to-end. **Candidly, it under-performed**: the cardboard flexed under the arm's own weight, joint play was ~5–10° at the elbow, and the gripper couldn't reliably pinch a ping-pong ball. Every mechanical trick (internal bracing, skewer spines, doubled-up walls) traded weight for rigidity and then ran out of both.

The software stack kept running through all of this — the prototype was a mechanical rigidity problem, not a design problem — but the demo story depends on the arm actually picking the block.

**The fix, packaged for the next iteration:** the repo now includes a complete set of printable SG90-arm parts under `3d-models/sg90-robot-arm-model_files/`:

- `SG90 robot/` — 37 part files covering the base, shoulder/elbow brackets, gripper housing, gripper jaws, gears, bucket + rail
- `SG90 housing/` — servo-mount brackets and housings (left/right mirrored)
- `.stl` + `.3mf` for printing, `.f3d` / `.f3z` for Fusion 360 edits
- A printable assembly PDF (`739870-sg90-robot-arm-...pdf`) as reference

Run the same code, the same config, the same servo channel map — just swap the cardboard frame for the printed parts and the arm moves the way the calibration math expects.

### Power discipline (learned the hard way)

Pi on its own 27W USB-C. Servos on a separate 5–6V rail. Common ground. Physical kill switch inline on the servo V+, tested with a multimeter before first power-up. See `docs/wiring.md`. See `docs/wiring.md`.

---

## 7. Software Stack

- **OS**: Raspberry Pi OS 64-bit (Debian Trixie), flashed headless with `custom.toml` (see the gotcha below)
- **Language**: Python 3.13 in a `--system-site-packages` venv so OpenCV + picamera2 system packages stay visible
- **Web**: FastAPI + Uvicorn, streaming MJPEG for the camera feed
- **Vision**: OpenCV HSV masking with morphological filtering and the largest-contour-wins heuristic; `red` wraps hue, so two ranges OR together
- **Motion**: `adafruit-circuitpython-pca9685` wrapped behind our own microsecond-level API, joint-limit clamps, thread-safe e-stop flag
- **TTS**: Piper (onnxruntime, CPU) with an `espeak-ng` fallback
- **Tooling**: ruff + black for formatting, pytest (+ pytest-cov) for tests, pre-commit for local hooks, GitHub Actions for CI

Two systemd units (`dumme-llama.service`, `dumme-app.service`) make the whole stack come up on boot — plug the Pi in, open the browser, demo works.

---

## 8. Engineering Quality

This is the part that isn't visible in a video but is what makes the submission real work.

- **76 unit + integration tests, 20 eval tests, 4 hardware smoke tests** — `pytest -m "unit or integration"` runs in ~1 s on a MacBook. `pytest -m eval` runs on the Pi and scores 18–20 out of 20 on the canonical utterances.
- **Coverage gate at 80%** on `dumme/`, currently at 84%. Real-hardware paths (camera open, TTS subprocess) live under the `hardware` marker, not the unit gate.
- **CI** on every push: ruff, ruff-format, black, pytest, coverage.xml upload.
- **Pre-commit** hooks: ruff, ruff-format, trailing-whitespace, large-file guard.
- **`scripts/preflight.sh`** — a 5-check shell script the team runs 5 minutes before demo: llama-server health, app health, PCA9685 I2C ack, `/dev/video0` present, OpenCV captures a non-uniform frame. Green = safe to present.
- **Makefile** with `make test`, `make eval`, `make smoke`, `make coverage`, `make demo` — every workflow is one command.
- **Docs** (`docs/` directory): pi_setup, plan, architecture, wiring, testing, demo_script, starting_point. New contributors can go from git clone to working Pi in under an hour.

---

## 9. What Tripped Us Up (And How We Fixed It)

A hackathon rarely goes smoothly. A selection:

1. **Android hotspot WPA3-only** → Pi OS's firstboot writes a WPA2-PSK `wpa_supplicant.conf` and silently fails to associate with WPA3-only APs. **Fix**: switched the hotspot to "WPA2/WPA3 transitional". Documented in `docs/pi_setup.md` so the next team doesn't lose 30 min.
2. **Debian Trixie switched to NetworkManager** → our first `firstrun.sh` wrote `/etc/wpa_supplicant/wpa_supplicant.conf` (which Trixie ignores). **Fix**: write an `.nmconnection` file directly into `/etc/NetworkManager/system-connections/` with chmod 600. Documented in Appendix A.
3. **cmdline.txt had no `systemd.run=` trigger** when we flashed with `dd` instead of the Imager GUI → `custom.toml` was present but never processed. **Fix**: wrote our own `firstrun.sh`, patched `cmdline.txt` manually. Documented.
4. **Gemma 4 isn't published as GGUF on Hugging Face yet** → we were ready to meet the "Gemma 4" prize criterion but couldn't. **Fix**: swapped to Gemma 3n E2B (same family, edge-optimized, validated by llama.cpp) with an explicit note. Prize story stays: Gemma, on-device, driving a physical robot.
5. **1.5 GB download over a phone hotspot would take 4 hours** at 100 KB/s. **Fix**: downloaded on a MacBook over real WiFi, then `scp`'d to the Pi on the local hotspot LAN (no cellular data used). Documented as an optimization in pi_setup.
6. **Pi 5 has no 3.5mm audio jack.** Would have bit us on the voice stretch. **Fix**: USB speaker on the BOM. Documented on the shopping list so nobody shows up without one.
7. **Cardboard frame flexed under load.** Arm would try to reach a calibrated `(r, θ)` but overshoot by several degrees because the elbow joint had 5–10° of play. **Fix**: printable SG90-arm parts checked into `3d-models/`. The electronics, config, and software are unchanged — swap the frame to fix the demo.

Every one of these went into `docs/pi_setup.md` §11 troubleshooting + Appendix A.

---

## 10. What's Next (if we had another day)

- **Real inverse kinematics**. Right now `Motion.pick(r_mm, θ)` accepts an `r_mm` but ignores it — it reaches a fixed pose. Replace with the calibration regression scaffolding that's already in the repo (`dumme/calibration/regression.py`).
- **Voice input via Vosk**. `dumme/io/mic.py` is the only remaining stub. 30 minutes of work to wire; blocked only because ambient noise at the venue needed real tuning.
- **Vertex AI fallback** for the occasional out-of-schema utterance, cached aggressively so we use < ₹100 of the GCP credit. The on-device-first story stays — cloud is the exception, not the default.
- **A second object class** (shape detection on top of color). HSV + contour roundness would get us "red ball vs red block".
- **Ultrasonic e-stop**: HC-SR04 → trip `Safety.estop` if the workspace is invaded mid-motion. The flag already exists; wiring is the only work.

---

## 11. Repo Map

```
dumme/          FastAPI app + all Python modules
config/         YAML configs + Gemma prompt template
static/         Browser UI (HTML + JS + CSS)
scripts/        preflight.sh + hardware smoke tools + prompt eval
tests/          unit + integration + eval + hardware tiers
systemd/        dumme-llama.service + dumme-app.service
docs/           pi_setup, plan, architecture, wiring, testing, demo_script, submission (this file)
models/         Gemma weights (gitignored, ~2.8 GB)
3d-models/      Printable SG90 arm + gripper parts (STL / 3MF / Fusion360)
.github/        CI workflow
```

---

## 12. Team

- _Name_ — _role_
- _Name_ — _role_
- _Name_ — _role_

---

## 13. Acknowledgements

- **Google & Raspberry Pi Foundation** for building the two pieces of kit that made this possible on a 1-day budget.
- **llama.cpp** contributors for keeping quantized GGUF inference fast on ARM.
- **Unsloth** for the Gemma 3n E2B GGUF upload.
- The **maker space that hosted the hackathon** for the cardboard, servos, and coffee.

---

*DummE runs 100% on-device on a 4 GB Raspberry Pi 5. No cloud. No latency. No privacy compromise. That's the story.*

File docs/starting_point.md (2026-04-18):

Based on the [official website of the Physical AI Hackathon 2026](https://physical-ai-hackthon.vercel.app/), here are the core tracks along with some of the most pressing real-world problems in each domain based on current industry and environmental data:

### 🌱 1. Sustainability & Climate (Green Tech)
*Focus: AI-powered environmental monitoring, resource optimization, and sensing systems.*
* **Extreme Weather Resilience:** As climate change accelerates, predicting and mitigating the impact of extreme weather (floods, wildfires, droughts) on physical assets and public utilities is a major challenge. 
* **Soil & Water Management:** Optimizing water availability and monitoring soil health (including organic carbon content) is critical for both agriculture and preventing environmental degradation.
* **Renewable Energy Optimization:** Monitoring and maintaining renewable energy assets (like solar panels and wind turbines) at the edge to prevent underperformance and failure.
* **Complex Environmental Data:** Collecting, cleaning, and analyzing massive datasets from varied environmental sensors to make real-time conservation decisions.

### ♿ 2. Accessibility (Inclusive Tech)
*Focus: Hardware + AI solutions empowering people with disabilities.*
* **Workplace & Educational Accommodations:** There is a severe lack of physical and digital tools that adapt in real-time to varied cognitive and physical needs, preventing Persons with Disabilities (PWD) from fully participating in tech and industrial workforces.
* **Independent Navigation:** Creating reliable, edge-AI powered spatial awareness tools (using computer vision) to help visually impaired individuals navigate dynamic physical environments safely.
* **Universal Interface Adaptation:** Designing physical input/output devices (alternative input devices, real-time speech-to-text displays) that can operate offline or in low-resource environments without requiring expensive, specialized setups.

### 🏙️ 3. Smart Infrastructure (Urban AI)
*Focus: Intelligent systems for cities, buildings, and public spaces.*
* **Fragmented Legacy Systems:** The biggest challenge in smart cities is retrofitting old physical infrastructure (roads, bridges, legacy power grids) with modern IT networks and sensors without causing massive disruptions.
* **Data Capacity & Edge Processing:** The sheer volume of data generated by thousands of city sensors overwhelms standard networks. Processing data locally (Edge AI) for things like traffic optimization is critical to reduce latency and bandwidth.
* **Privacy & Cybersecurity:** As public spaces become heavily monitored by sensors and cameras, maintaining citizen privacy and securing these smart networks against cyberattacks is a massive priority.

### 🔒 4. Safety & Automation (Safety)
*Focus: Real-time detection, anomaly identification, and automated response systems.*
* **Industrial and Machinery Accidents:** Preventing severe injuries in factories and warehouses by using AI-powered machine guarding to instantly halt equipment (like conveyors or cranes) when a human enters a danger zone.
* **PPE & Compliance Enforcement:** Real-time, automated monitoring to ensure that workers are wearing the correct Personal Protective Equipment (PPE) in hazardous environments.
* **Hazardous Environment Monitoring:** Instantaneous detection of anomalies like chemical leaks, fire, or smoke in industrial settings using localized sensor data and computer vision.

### 🌾 5. Agriculture & Rural (AgriTech)
*Focus: Edge AI for crop monitoring, soil analysis, and precision agriculture.*
* **Hyper-Local Climate Vulnerability:** Smallholder farmers lack the tools to accurately predict and respond to hyper-local weather shifts, droughts, and flooding, leading to massive crop losses.
* **Resource & Infrastructure Limitations:** Rural areas often suffer from poor internet connectivity and lack of reliable electricity, meaning agricultural tech must be low-power and capable of running entirely offline (TinyML/Edge AI).
* **Precision Agriculture Affordability:** Modern automated farming (like targeted pesticide spraying or automated disease detection) is often too expensive. There is a pressing need for cheap, accessible hardware/AI combinations that can diagnose plant diseases or assess soil moisture on a budget.

### ✨ 6. Open Challenge
*Focus: Your domain, your problem.*
* *Problems in this track are entirely open-ended, provided they use AI integrated with physical hardware to solve a tangible, real-world issue.*

## Final Project Idea

- Build an edge-computing assistant robot named `DummE` using a Raspberry Pi as the on-device brain.
- The robot will process sensor and camera inputs locally for low-latency decisions, reduced cloud dependence, and better privacy.
- It can support household and lab assistance tasks such as object detection, obstacle awareness, and basic autonomous movement using the existing hardware inventory.

## Inventory List

| Part Name | Description/Model | Quantity |
| --- | --- | --- |
| Single Board Computer | Raspberry Pi 5 (4GB RAM) | 1 |
| Camera Module | Raspberry Pi Camera Module | 1 |
| Microcontroller | ESP32 | 1 |
| Microcontroller | Arduino Uno | 1 |
| Servo Motor | MG90S Micro Servo | 2 |
| Servo Motor | SG90 Micro Servo | 4 |
| Servo Motor | MG995 High Torque Servo | 6 |
| Servo Driver | PCA9685 16-Channel 12-Bit PWM Driver | 1 |
| GPS Module | NEO-6M (GY-GPS6MV2) | 1 |
| Ultrasonic Sensor | HC-SR04 | 1 |
| Temp/Humidity Sensor | DHT22 (AM2302) | 1 |
| Temp/Humidity Sensor | DHT11 | 2 |
| IR Sensor | HW-201 Obstacle Avoidance | 1 |
| Load Cell Amplifier | HX711 | 1 |
| IMU Sensor | MPU6050 (GY-521) Accelerometer/Gyroscope | 1 |
| Barometric Sensor | BME280 / BMP280 | 1 |

## Additional Notes

- We also have `$5` in GCP credits.
- The prize will prioritize ideas that use the `Gemma 4` model and GCP products when possible.

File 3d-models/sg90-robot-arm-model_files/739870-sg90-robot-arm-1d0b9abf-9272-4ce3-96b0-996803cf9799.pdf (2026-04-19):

## SG90 robot arm

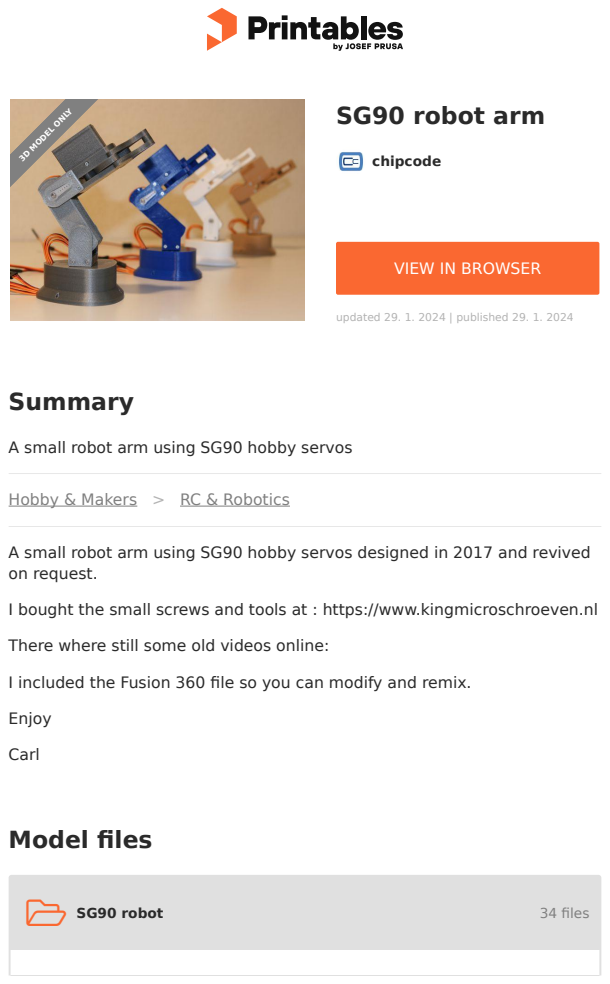
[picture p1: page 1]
Model files; Summary; Hobby & Makers; RC & Robotics; Enjoy; Carl; SG90 robot; 34 files; chipcode; updated 29. 1. 2024 | published 29. 1. 2024; 3D MODEL ONLY

VIEW IN BROWSER (https://printables.com/model/739870-sg90-robot-arm)

A small robot arm using SG90 hobby servos

A small robot arm using SG90 hobby servos designed in 2017 and revived
on request.

I bought the small screws and tools at : https://www.kingmicroschroeven.nl

There where still some old videos online:

I included the Fusion 360 file so you can modify and remix.

sg90-robot-base.f3z

sg90-robot-base.stl

sg90-robot-base.3mf

sg90-gripper.f3d

sg90-gripper-gear-right.stl

sg90-gripper-base-top.stl

sg90-gripper-bar-left.stl

sg90-gripper-housing.stl

sg90-gripper-base-bottom.stl

sg90-gripper-bar-right.stl sg90-gripper-gear-left.stl

sg90-gripper-right-bottom.stl

sg90-gripper-left-bottom.stl

sg90-gripper-right-top.stl

sg90-gripper-left-top.stl

sg90-gripper-gear-horn.stl

sg90-gripper-bracket-right.stl

sg90-gripper-bracket-left.stl

sg90-gripper-bar-right.3mf

sg90-gripper-left-top.3mf sg90-gripper-left-bottom.3mf

sg90-gripper-right-bottom.3mf

sg90-gripper-base-top.3mf

sg90-gripper-bracket-right.3mf

sg90-gripper-gear-right.3mf

sg90-gripper-base-bottom.3mf

sg90-gripper-right-top.3mf

sg90-gripper-bar-left.3mf

sg90-gripper-gear-left.3mf

sg90-gripper-gear-horn.3mf

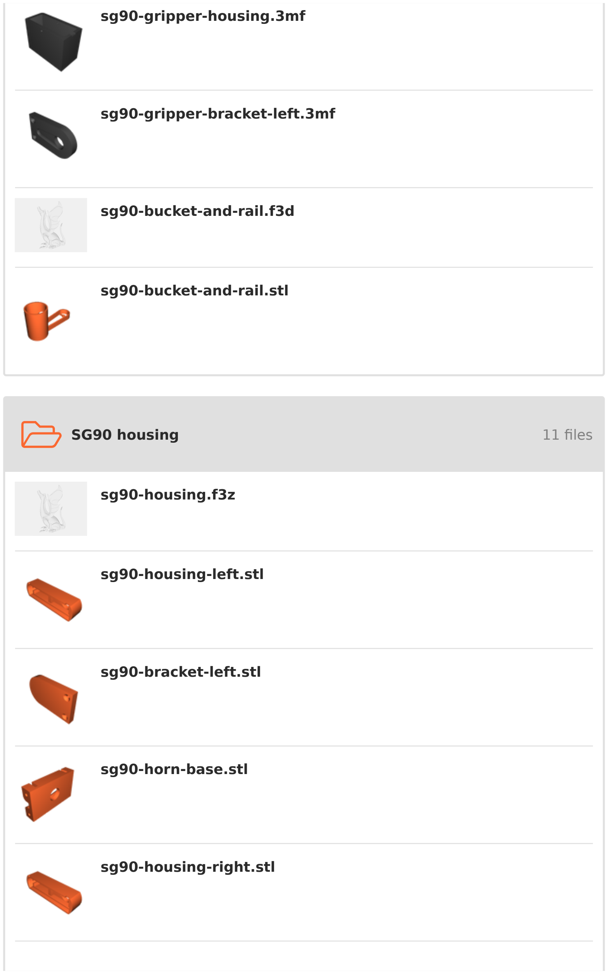
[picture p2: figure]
SG90 housing; 11 files; sg90-gripper-housing.3mf; sg90-gripper-bracket-left.3mf; sg90-bucket-and-rail.f3d; sg90-bucket-and-rail.stl; sg90-housing.f3z; sg90-housing-left.stl; sg90-bracket-left.stl; sg90-horn-base.stl; sg90-housing-right.stl

# Other files

- SG90 robot | 1 file

sg90-bracket-right.stl

sg90-housing-left.3mf

sg90-horn-base.3mf

sg90-housing-right.3mf

sg90-bracket-right.3mf

sg90-bracket-left.3mf

readme.txt

## License

This work is licensed under a

Creative Commons (4.0 International License)

Attribution (http://creativecommons.org/licenses/by/4.0/)

✖ | Sharing without ATTRIBUTION
✔ | Remix Culture allowed
✔ | Commercial Use
✔ | Free Cultural Works
✔ | Meets Open Definition

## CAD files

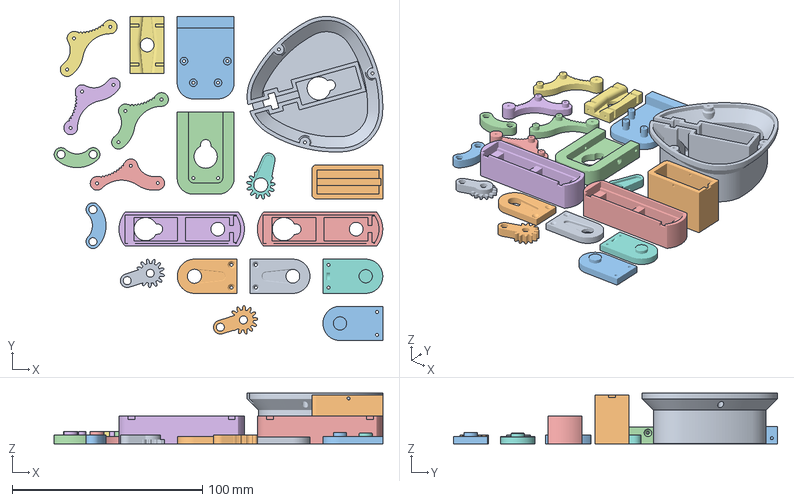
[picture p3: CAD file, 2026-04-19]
3d-models/sg90-robot-arm-model_files/SG90 housing/sg90 full .3mf
172.9 x 170.5 x 26.7 mm
SG90 robot base
SG90 gripper housing
SG90 gripper base bottom
SG90 gripper base top
SG90 housing left x 2
SG90 horn base
SG90 bracket left
SG90 bracket right
SG90 gripper bracket left
SG90 gripper bracket right
SG90 gripper right top
SG90 gripper right bottom
SG90 gripper left top
SG90 gripper left bottom
SG90 gripper gear horn
SG90 gripper gear right
SG90 gripper gear left
SG90 gripper bar right
SG90 gripper bar left

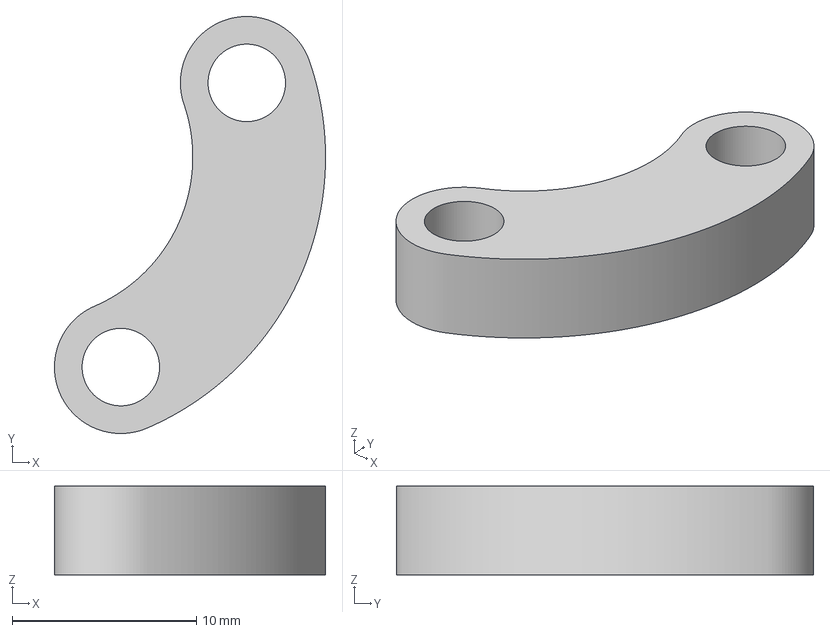
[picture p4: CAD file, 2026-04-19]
3d-models/sg90-robot-arm-model_files/SG90 robot/sg90-gripper-bar-right.3mf
14.7 x 22.6 x 4.80 mm

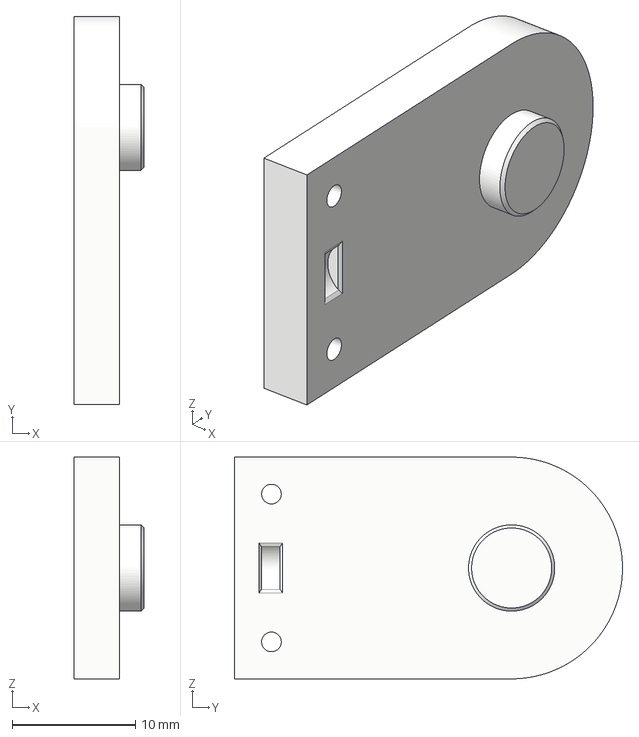
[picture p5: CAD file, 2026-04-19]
3d-models/sg90-robot-arm-model_files/SG90 housing/sg90-bracket-left.3mf
5.70 x 31.5 x 18.0 mm

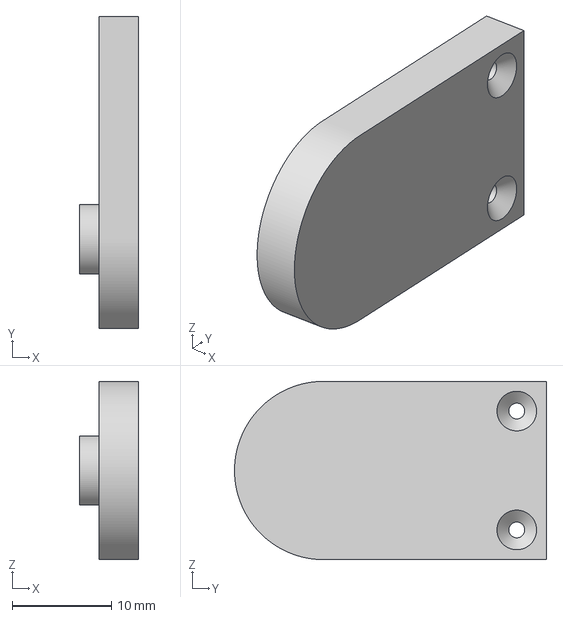
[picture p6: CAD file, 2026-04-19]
3d-models/sg90-robot-arm-model_files/SG90 robot/sg90-gripper-bracket-right.3mf
6.00 x 31.5 x 18.0 mm

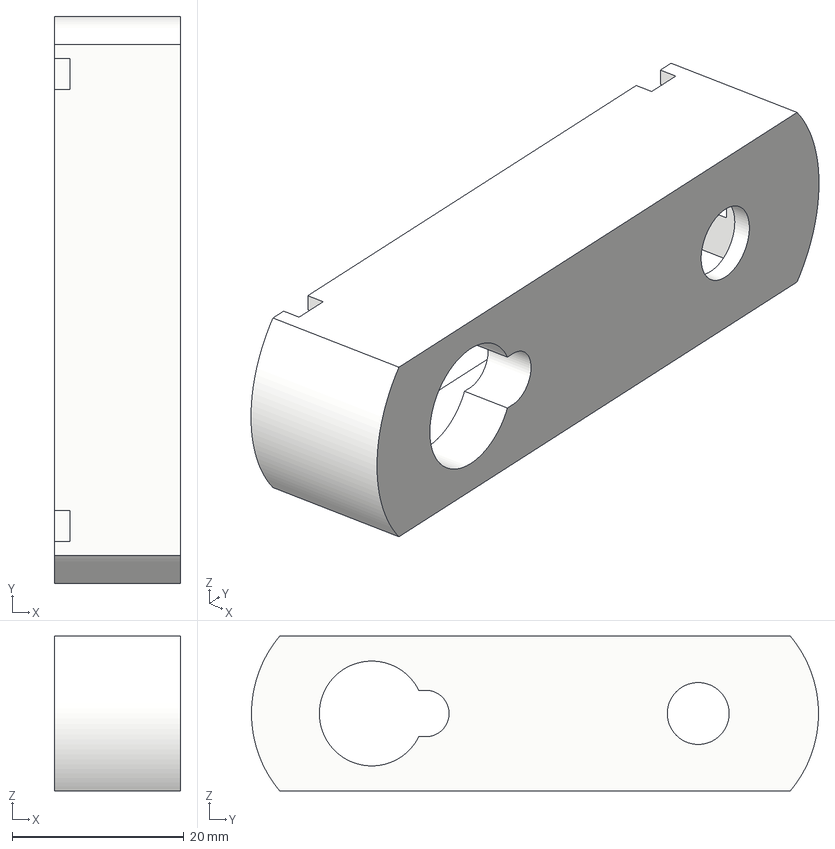
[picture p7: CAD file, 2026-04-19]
3d-models/sg90-robot-arm-model_files/SG90 housing/sg90-housing-right.3mf
14.7 x 66.0 x 18.0 mm

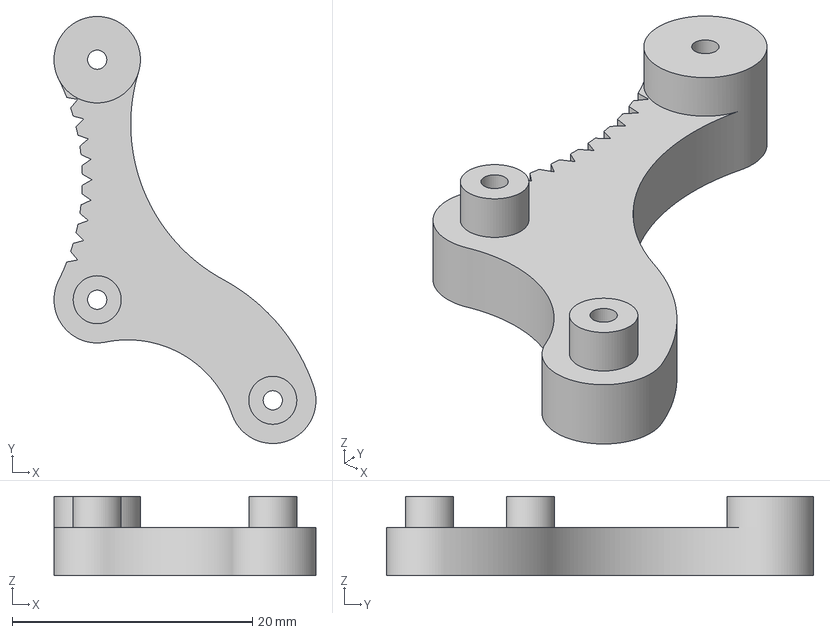
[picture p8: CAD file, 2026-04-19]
3d-models/sg90-robot-arm-model_files/SG90 robot/sg90-gripper-right-top.3mf
21.8 x 35.6 x 6.60 mm

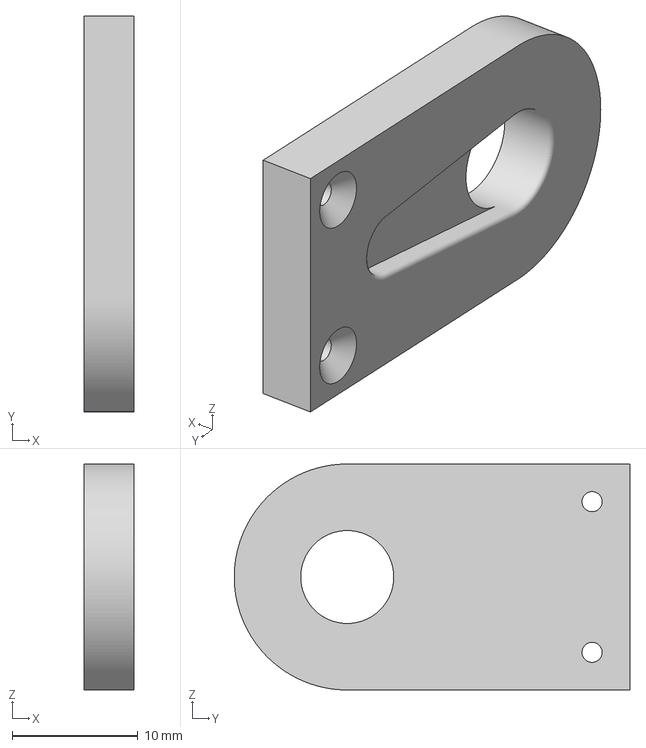
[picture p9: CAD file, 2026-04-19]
3d-models/sg90-robot-arm-model_files/SG90 robot/sg90-gripper-bracket-left.3mf
4.00 x 31.5 x 18.0 mm

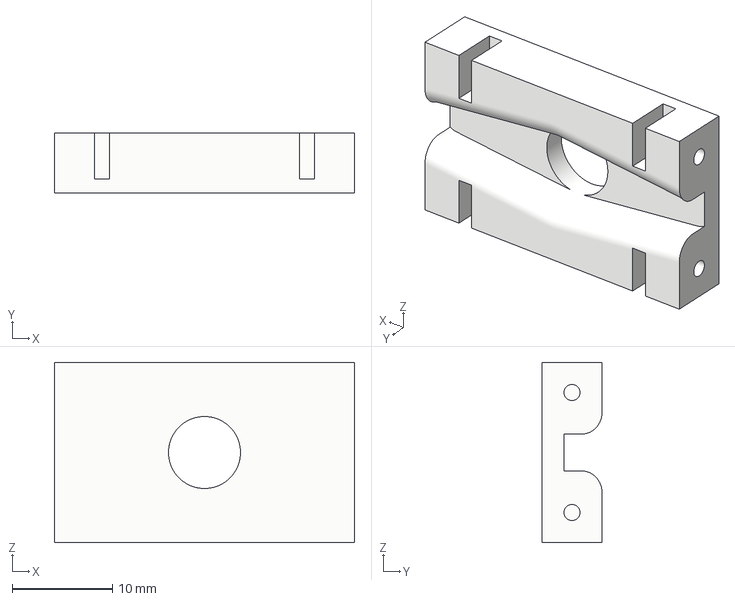
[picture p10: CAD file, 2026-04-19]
3d-models/sg90-robot-arm-model_files/SG90 housing/sg90-horn-base.3mf
30.0 x 6.00 x 18.0 mm

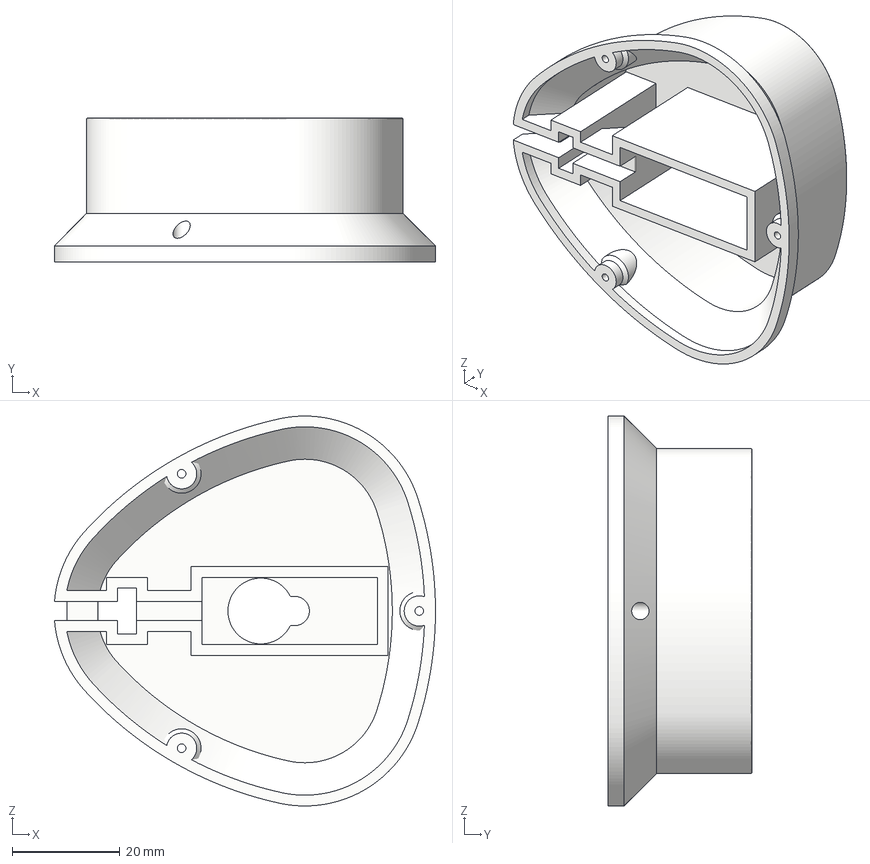
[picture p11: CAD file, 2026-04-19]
3d-models/sg90-robot-arm-model_files/SG90 robot/sg90-robot-base.3mf
70.6 x 26.7 x 72.2 mm

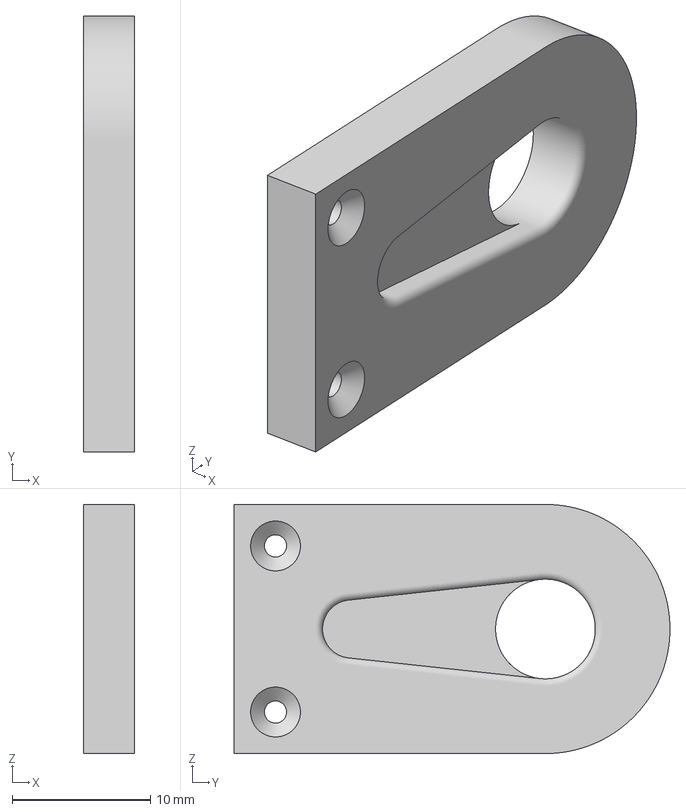
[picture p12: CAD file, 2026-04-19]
3d-models/sg90-robot-arm-model_files/SG90 housing/sg90-bracket-right.3mf
3.70 x 31.5 x 18.0 mm

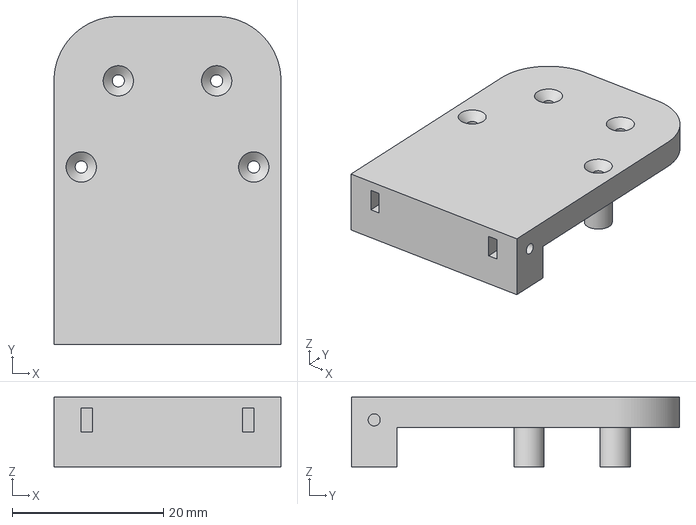
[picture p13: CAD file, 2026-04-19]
3d-models/sg90-robot-arm-model_files/SG90 robot/sg90-gripper-base-bottom.3mf
30.0 x 43.4 x 9.20 mm

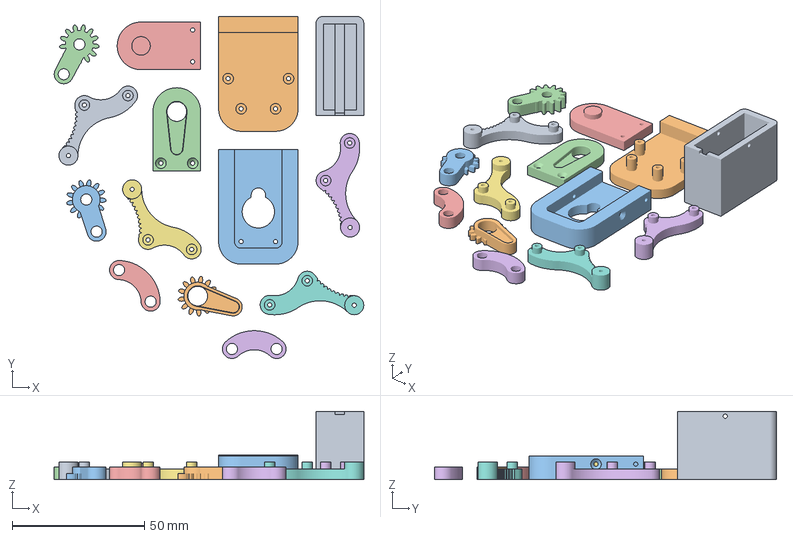
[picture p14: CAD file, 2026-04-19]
3d-models/sg90-robot-arm-model_files/SG90 robot/sg90-gripper-bar-left.3mf
116.9 x 129.1 x 25.7 mm
SG90 gripper housing
SG90 gripper base bottom
SG90 gripper base top
SG90 gripper bracket left
SG90 gripper bracket right
SG90 gripper right bottom
SG90 gripper right top
SG90 gripper left bottom
SG90 gripper left top
SG90 gripper gear horn
SG90 gripper gear right
SG90 gripper gear left
SG90 gripper bar right
SG90 gripper bar left

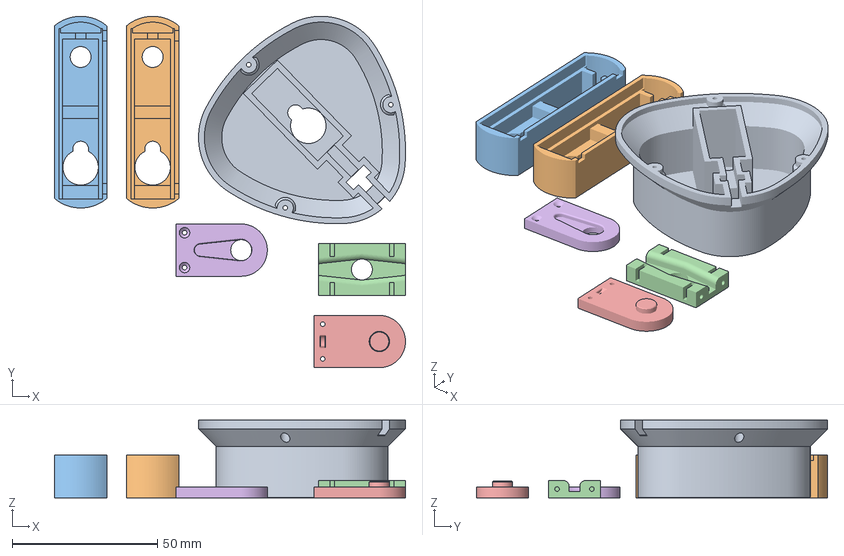
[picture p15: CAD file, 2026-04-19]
3d-models/sg90-robot-arm-model_files/SG90 robot/Goo-Base.3mf
120.9 x 121.0 x 26.7 mm
SG90 robot base
SG90 housing left x 2
SG90 horn base
SG90 bracket left
SG90 bracket right

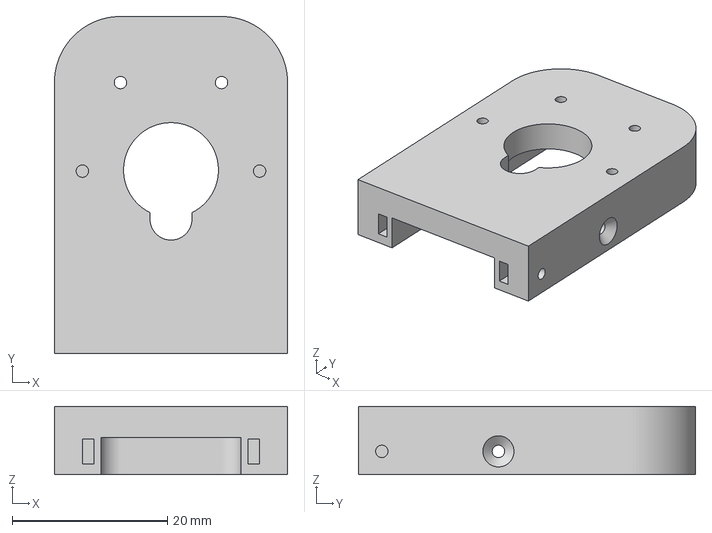
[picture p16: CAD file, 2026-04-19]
3d-models/sg90-robot-arm-model_files/SG90 robot/sg90-gripper-base-top.3mf
30.0 x 43.4 x 8.80 mm

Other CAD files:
3d-models/sg90-robot-arm-model_files/SG90 housing/sg90-housing-left.3mf
3d-models/sg90-robot-arm-model_files/SG90 robot/sg90-gripper-left-top.3mf
3d-models/sg90-robot-arm-model_files/SG90 robot/sg90-gripper-left-bottom.3mf
3d-models/sg90-robot-arm-model_files/SG90 robot/sg90-gripper-right-bottom.3mf
3d-models/sg90-robot-arm-model_files/SG90 housing/sg90-bracket-left.stl
3d-models/sg90-robot-arm-model_files/SG90 housing/sg90-bracket-right.stl
3d-models/sg90-robot-arm-model_files/SG90 housing/sg90-horn-base.stl
3d-models/sg90-robot-arm-model_files/SG90 housing/sg90-housing-left.stl
3d-models/sg90-robot-arm-model_files/SG90 housing/sg90-housing-right.stl
3d-models/sg90-robot-arm-model_files/SG90 housing/sg90-housing.f3z
3d-models/sg90-robot-arm-model_files/SG90 robot/GripperFul.3mf
3d-models/sg90-robot-arm-model_files/SG90 robot/sg90-bucket-and-rail.f3d
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

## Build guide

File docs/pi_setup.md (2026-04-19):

# DummE — Pi Setup & Shopping Guide

> Everything to buy, flash, and configure **before hack day**. Works headless from a MacBook — no monitor or keyboard needed. Follow top to bottom.

---

## 1. Shopping List

### 1.1 Essentials (must-have before hack day)

| Item | Why | Approx ₹ |
|---|---|---|
| **Samsung EVO Plus 64GB microSD** (A2/V30) | Storage — chosen for random-IOPS speed | ~₹700 |
| **Pi 5 Official 27W USB-C PSU** (5V/5A) | Pi 5 brown-outs on weaker supplies; Pi 4 chargers **do not** work | ~₹1,500 |
| **Pi 5 Active Cooler** (official fan + heatsink) | Pi 5 throttles hard under LLM load — non-optional for Gemma | ~₹500 |
| **USB-C microSD card reader** | For flashing the card from MacBook (skip if your Mac has an SD slot + microSD adapter) | ~₹300 |
| **4×AA battery holder + 4 AA batteries** *(or 5V 3A UBEC)* | **Separate servo power rail** — mandatory, never share Pi's 5V | ~₹200 |
| **Jumper wires**: 40× M-F, 40× M-M, 20× F-F | Every connection on the build | ~₹300 |
| **Mini breadboard** (400-point) | Consolidating grounds + power rails | ~₹150 |
| **Hot glue gun + 10 sticks** | Cardboard joinery (prototype only — see note) | ~₹400 |
| **Bamboo skewers or chopsticks** | Internal bracing for arm segments (prototype only) | ~₹50 |
| **5-ply corrugated cardboard** (~1 sqm) | Prototype frame material | scrap |

> **Prototype note** — The cardboard frame is fine for electronics bring-up but flexes under the arm's own weight (~5–10° of joint slop at the elbow). For a sturdy build, print the parts in [`3d-models/sg90-robot-arm-model_files/`](../3d-models/sg90-robot-arm-model_files/) instead: STL + 3MF for any slicer, Fusion 360 sources (`*.f3d`, `*.f3z`) if you want to edit, plus a printable assembly PDF. The servo channel map and `config/servos.yaml` don't change.
| **SPST toggle switch** (5A rated) | Inline kill switch on servo V+ — you WILL need it | ~₹50 |
| **M2 / M3 screws + washers** | Servo mounting (most SG90s ship with these — check first) | — |

### 1.2 Demo-Day Props

| Item | Why |
|---|---|
| Ping-pong ball + small foam cubes in **red, blue, green** | Target objects for pick-and-place |
| 3–4 small coloured cups/bowls | Destinations |
| Desk lamp | Even lighting kills HSV flakiness |
| White A3 paper or foam board | Workspace backdrop — huge win for colour detection |

### 1.3 Camera (pick one)

| Item | Why | Notes |
|---|---|---|
| **Raspberry Pi Camera Module** | CSI ribbon, lowest latency, native `picamera2` path | Default per BOM. Ribbon blue-tab faces ethernet. |
| **USB UVC webcam** | Works out of the box via OpenCV V4L2, appears as `/dev/video0` | Current build uses this. No CSI wiring needed. |

### 1.4 Voice Stretch (skip unless P2 is green by hour 7)

| Item | Why |
|---|---|
| Cheap USB microphone | Pi 5 has no onboard mic input |
| USB speaker (or 3.5mm powered speaker + USB audio dongle) | ⚠️ **Pi 5 removed the 3.5mm audio jack** — you cannot just plug headphones in |

### 1.5 Nice-to-Have (debugging lifesavers)

| Item | Why |
|---|---|
| Ethernet cable | Fallback if WiFi is flaky on demo day |
| Multimeter | Debugs power issues in 30 seconds instead of 30 minutes |
| 1–2 extra SG90 servos | Burnouts happen during calibration |

---

## 2. Flash the SD Card from MacBook (Headless)

### 2.1 Install Raspberry Pi Imager

```bash
brew install --cask raspberry-pi-imager
```

Or download the `.dmg` from [raspberrypi.com/software](https://www.raspberrypi.com/software/).

### 2.2 Flash Pi OS with headless config baked in

1. Insert the 64GB microSD (via reader) into your MacBook.
2. Open **Raspberry Pi Imager**.
3. **Choose Device** → `Raspberry Pi 5`.
4. **Choose OS** → `Raspberry Pi OS (64-bit)` — Trixie (Debian 13) as of writing. Use the full-with-desktop variant; enables VNC later if you need it.
5. **Choose Storage** → the 64GB card.
6. Click **Next** → when prompted "Would you like to apply OS customisation settings?" → **EDIT SETTINGS**. This step is the entire game.

   **General tab**:
   - ✅ Set hostname: `dumme` (reachable as `dumme.local`)
   - ✅ Set username: `dumme` + a strong password (save it to `pi-passwords.txt` — gitignored)
   - ✅ Configure wireless LAN: your WiFi SSID + password + **country code** (`IN`, `AE`, etc.)
   - ✅ Set locale: `Asia/Kolkata` (or `Asia/Dubai`), keyboard `us`

   > ⚠️ If your WiFi is WPA3-only (common on recent Android hotspots), switch it to **WPA2-Personal** or **WPA2/WPA3 transitional** — Pi OS firstboot writes a WPA2-PSK config and silently fails to join WPA3-only APs.
   > ⚠️ If you flash with `dd` instead of the Imager GUI, see Appendix A (at the bottom of this doc) for how to wire up `firstrun.sh` + `cmdline.txt` manually.

   **Services tab**:
   - ✅ Enable SSH → **Use password authentication** (simplest for hackathon)

   **Options tab**:
   - ✅ Eject media when finished

7. **Save** → **Yes** to apply → your Mac password → wait ~5 min for flash + verify.

### 2.3 Boot the Pi

1. Eject the card, slot it into the Pi 5 (underside).
2. Plug in the **27W USB-C PSU**.
3. Green LED blinks steadily → booting. First boot takes **~2–3 minutes** while the filesystem expands.

---

## 3. Find and SSH into the Pi

From your MacBook Terminal:

```bash
ping dumme.local
```

If it resolves → you're in business. If not:

```bash
brew install nmap
sudo nmap -sn 192.168.1.0/24        # adjust subnet to your LAN
# Look for the Pi by vendor name "Raspberry Pi"
```

Once you have the hostname or IP:

```bash
ssh dumme@dumme.local
# or
ssh dumme@<ip-address>
```

Type `yes` at the fingerprint prompt, then your password.

### 3.1 Passwordless SSH (recommended, 30 seconds)

```bash
# On MacBook:
ssh-keygen -t ed25519        # skip if you already have a key
ssh-copy-id dumme@dumme.local
```

Never type the password again. Do this from every teammate's laptop so all three can log in.

---

## 4. First-Run System Config

Once SSHed in:

```bash
# Update everything
sudo apt update && sudo apt full-upgrade -y

# Install baseline tooling
sudo apt install -y git python3-pip python3-venv i2c-tools \
                    build-essential cmake wget curl

# Enable hardware interfaces non-interactively
sudo raspi-config nonint do_i2c 0       # I2C on (for PCA9685)
sudo raspi-config nonint do_spi 0       # SPI on
# CSI camera: no-op on Bookworm/Trixie — libcamera + picamera2 just work.
# USB UVC camera: also no-op — kernel exposes it as /dev/video0 automatically.

# Reboot so changes apply cleanly
sudo reboot
```

Wait ~30 sec, SSH back in.

Verify I2C (once PCA9685 is wired later):

```bash
i2cdetect -y 1
# Should show "40" in the grid when PCA9685 is connected
```

---

## 5. Dev Environment from MacBook (no monitor, forever)

### 5.1 VS Code Remote-SSH

1. Install **VS Code** on MacBook.
2. Install the **Remote - SSH** extension.
3. `Cmd+Shift+P` → `Remote-SSH: Connect to Host...` → enter `dumme@dumme.local`.
4. VS Code now runs against the Pi. Edit files, open terminals, debug Python — all as if local.

All three teammates can connect to the same Pi simultaneously. No monitor, no keyboard, no VNC.

### 5.2 Project Directory + Python venv

Easiest: rsync the repo from your Mac (avoids setting up a GitHub deploy key on the Pi).

```bash
# On Mac — from the repo root
rsync -az --exclude '.venv' --exclude '.git' --exclude 'models/*.gguf' \
      --exclude '__pycache__' --exclude '.env' --exclude 'pi-passwords.txt' \
      ./ dumme@dumme.local:/home/dumme/dumme/
```

Then on the Pi:

```bash
cd ~/dumme
# --system-site-packages lets the venv see apt-installed picamera2.
python3 -m venv --system-site-packages .venv
source .venv/bin/activate

pip install --upgrade pip
pip install -r requirements.txt    # fastapi, opencv, adafruit-*, piper-tts, ...
```

Add the venv auto-activate to `.bashrc` so SSH sessions land inside it:

```bash
grep -q 'source ~/dumme/.venv/bin/activate' ~/.bashrc \
  || echo 'source ~/dumme/.venv/bin/activate' >> ~/.bashrc
```

### 5.3 Passwordless sudo for the `dumme` user

Raspberry Pi OS (post-Bookworm) no longer ships a default passwordless-sudo file for non-`pi` users. Add one so the rest of setup doesn't prompt:

```bash
echo "dumme ALL=(ALL) NOPASSWD:ALL" | sudo tee /etc/sudoers.d/010_dumme-nopasswd
sudo chmod 440 /etc/sudoers.d/010_dumme-nopasswd
```

---

## 6. Build llama.cpp + Download Gemma

### 6.1 Build llama.cpp

```bash
cd ~
git clone --depth=1 https://github.com/ggml-org/llama.cpp
cd llama.cpp
cmake -B build -DGGML_NATIVE=ON
cmake --build build -j4
# ~5–8 minutes on Pi 5
```

```bash
./build/bin/llama-cli --version
```

### 6.2 Download Gemma 3n E2B Q4_K_M (~2.8 GB)

Gemma 3n is the current edge-friendly variant supported by llama.cpp; it's the model we've validated on Pi 5.

```bash
mkdir -p ~/dumme/models && cd ~/dumme/models
wget -O gemma-3n-E2B-it-Q4_K_M.gguf \
  'https://huggingface.co/unsloth/gemma-3n-E2B-it-GGUF/resolve/main/gemma-3n-E2B-it-Q4_K_M.gguf'
```

> ⚠️ **On a phone hotspot this download is punishing** (several hours at ~400 KB/s). Two faster options:
> 1. Download on the Mac over real WiFi, then `scp` to the Pi over Hephaestus — the hotspot hop is LAN-only and much quicker than an internet-bridged one.
> 2. Use a USB stick — Mac to stick to Pi is ~1 min each way.

### 6.3 Smoke-test Gemma

```bash
~/llama.cpp/build/bin/llama-cli \
  -m ~/dumme/models/gemma-3n-E2B-it-Q4_K_M.gguf \
  --ctx-size 1024 \
  --threads 4 \
  -p "Return ONLY valid JSON: {\"status\": \"ok\"}" \
  --n-predict 20 --no-conversation
```

First load mmaps ~3 GB and can take 30–60 s; subsequent prompts are faster.

### 6.4 Run llama-server (what the app actually hits)

Production path: enable the systemd service (see §8).

Ad-hoc path:

```bash
~/llama.cpp/build/bin/llama-server \
  -m ~/dumme/models/gemma-3n-E2B-it-Q4_K_M.gguf \
  --ctx-size 2048 \
  --threads 4 \
  --host 127.0.0.1 \
  --port 8080
```

From another SSH session:

```bash
curl -sf http://127.0.0.1:8080/health
# → {"status":"ok"}

curl -s http://127.0.0.1:8080/v1/chat/completions \
     -H 'Content-Type: application/json' \
     -d '{"messages":[{"role":"user","content":"Say only OK."}],"max_tokens":10}' \
     | python3 -m json.tool
```

If `/health` is `ok` and the chat endpoint returns text, the LLM stack is done.

---

## 7. GitHub Setup (so all 3 devs can push)

```bash
# On the Pi
git config --global user.name  "DummE Team"
git config --global user.email "dumme@hackathon.local"

ssh-keygen -t ed25519 -C "dumme-pi"
cat ~/.ssh/id_ed25519.pub
# Paste this into GitHub → Settings → SSH and GPG keys → New SSH key
```

Each teammate also adds their own Mac's SSH key to GitHub and clones directly onto the Pi via VS Code Remote.

---

## 8. systemd services (autostart on boot)

Install the two unit files that ship in the repo and enable them:

```bash
sudo cp ~/dumme/systemd/dumme-llama.service /etc/systemd/system/
sudo cp ~/dumme/systemd/dumme-app.service   /etc/systemd/system/
sudo systemctl daemon-reload
sudo systemctl enable --now dumme-llama.service
sudo systemctl enable --now dumme-app.service

systemctl status dumme-llama.service dumme-app.service --no-pager
```

Logs:

```bash
journalctl -u dumme-llama.service -n 50 --no-pager
journalctl -u dumme-app.service   -n 50 --no-pager
```

Both services expect the code at `/home/dumme/dumme/` and the venv at
`/home/dumme/dumme/.venv`. Update the unit files if you deployed elsewhere.

---

## 9. Power Wiring (read before plugging anything in)

```
              ┌──────────────┐
              │  Pi 5 brain  │
              └──────┬───────┘
                     │ I2C (SDA/SCL)
              ┌──────▼───────┐      ┌──────────────┐
              │   PCA9685    │◄──── │  4×AA pack   │  5–6V
              │   16-ch PWM  │      │  (servo V+)  │
              └──┬───────────┘      └──────┬───────┘
                 │ 5 PWM lines             │
         ┌───────┴────────┐                │
         │                │                │
     5 servos          GND ──────────┬─────┘
                                     │
                              ┌──────┴──────┐
                              │   KILL      │  ← SPST toggle on V+
                              │   SWITCH    │     between battery + PCA9685
                              └─────────────┘
```

**Rules, in order of how badly they'll burn you:**

1. **Never** power servos from the Pi's 5V pin. They will brown out the CPU mid-LLM-inference.
2. **Always** share ground between the Pi and the servo rail. Floating grounds = erratic PWM = dancing arm.
3. **Always** wire the kill switch inline on V+. During calibration, an SG90 going full-range into a stuck joint will burn out in seconds.
4. **Always** feed PCA9685's `V+` from the battery, and its `VCC` from the Pi's 3.3V (logic). Two separate supplies, two separate jobs.

---

## 10. Pre-Flight Verification (run 24 hrs before hack day)

Run the automated check:

```bash
bash scripts/preflight.sh
```

It covers the machine-verifiable items below. Tick the manual ones by hand.

**Automated** (by `preflight.sh`):
- [ ] `llama-server` `/health` responds on `http://127.0.0.1:8080`.
- [ ] FastAPI app `/status` responds on `http://127.0.0.1:8000`.
- [ ] `i2cdetect -y 1` shows `0x40` (PCA9685).
- [ ] `/dev/video0` is present.
- [ ] `cv2.VideoCapture(0).read()` returns a frame.

**Manual:**
- [ ] `ssh dumme@dumme.local` works from every teammate's Mac.
- [ ] VS Code Remote-SSH opens the Pi.
- [ ] `models/gemma-3n-E2B-it-Q4_K_M.gguf` exists and is ~2.8 GB.
- [ ] Gemma completion latency is ≤ 5 s for a 20-token reply.
- [ ] Piper TTS plays a test phrase through the USB speaker (stretch).
- [ ] Kill switch physically cuts servo power (test with multimeter).
- [ ] Pi stays under 80 °C after a 10-minute LLM load test (`vcgencmd measure_temp`).
- [ ] `pytest` is green; `pytest -m eval` scores ≥ 18/20.

---

## 11. Troubleshooting Cheatsheet

| Symptom | Likely cause | Fix |
|---|---|---|
| `ping dumme.local` times out | mDNS blocked, wrong country code, or WPA3-only AP | SSH by IP; switch hotspot to WPA2; re-flash with correct WiFi country |
| SSH permission denied | Key not copied, or password from Imager wrong | Re-copy key (`ssh-copy-id dumme@dumme.local`); check `pi-passwords.txt` |
| Pi never joins WiFi | `cmdline.txt` missing `systemd.run=firstrun.sh` (dd-flash only) | See Appendix A for the manual wiring |
| Pi reboots mid-inference | Under-powered PSU | Use the **27W** official PSU, not a Pi 4 charger |
| Pi hits 85 °C and throttles | No active cooler | Install the Active Cooler, rerun |
| PCA9685 not found on I2C | I2C not enabled, or SDA/SCL swapped | `sudo raspi-config nonint do_i2c 0`, check wiring |
| USB camera not at `/dev/video0` | Hub/cable issue | `lsusb` should show a UVC-class device; `v4l2-ctl --list-devices` confirms the node |
| `picamera2` import error | Pi Camera ribbon backwards | If using CSI: flip ribbon, blue tab faces ethernet |
| Servos twitch at rest | No PWM release after motion | `Motion.release_all()` (sets PWM=0) |
| Gemma returns garbage | Context too long, prompt missing few-shots | Keep `--ctx-size 2048`; check `config/prompts/command_parser.txt` |
| `llama-server` OOM killed | 4 GB Pi + wrong quant | Use `Q4_K_M`; check `free -h`; `OOMScoreAdjust=500` in the unit file |
| Hotspot isolates the Pi | Venue WiFi blocks client↔client | Use a phone hotspot, not venue WiFi, for Mac↔Pi traffic |

---

## Appendix A — dd-based flash (no Imager GUI)

Sometimes the GUI is blocked (no admin on the Mac, CI, automated setup). You can still flash headlessly:

```bash
# On Mac
curl -L -o /tmp/pi-os.img.xz \
  'https://downloads.raspberrypi.com/raspios_arm64_latest'
diskutil list external physical            # find the SD card → /dev/diskN
diskutil unmountDisk /dev/diskN
xz -dc /tmp/pi-os.img.xz | sudo dd of=/dev/rdiskN bs=4m status=progress
```

Then write `firstrun.sh` + patch `cmdline.txt` on the boot partition — an example `firstrun.sh` that configures hostname, user, SSH, and a NetworkManager WiFi profile lives at [scripts/preflight.sh](../scripts/preflight.sh) neighbourhood (check git history of `boot-partition-firstrun.sh` if you need a template). Essence:

```
systemd.run=/boot/firmware/firstrun.sh systemd.run_success_action=reboot systemd.unit=kernel-command-line.target
```

appended to `cmdline.txt`. `firstrun.sh` writes `/etc/NetworkManager/system-connections/<SSID>.nmconnection` (chmod 600), sets the hostname, enables SSH, and `rm`s itself at the end. See the troubleshooting note above for why plain `wpa_supplicant.conf` no longer works on Trixie.

---

**Once the preflight script is green and every manual box ticked, you're ready to start the hack.** From that point, follow `plan.md` for the build itself.

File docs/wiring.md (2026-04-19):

# DummE — Wiring Reference

Quick reference for every physical connection. **Read [`pi_setup.md`](./pi_setup.md) §9 (Power Wiring) before plugging anything in.**

## Power Rails

```
┌─────────────────┐        ┌──────────────────────────────┐
│ 27W USB-C PSU   │──── 5V ┤ Pi 5 (USB-C input)           │
│ (Pi only)       │        │ Logic, camera, llama-server  │
└─────────────────┘        └──────────────────────────────┘

┌─────────────────┐        ┌──────────────────────────────┐
│ 4×AA (6V) OR    │── 5–6V ┤ PCA9685 V+ (servo rail)      │
│ 5V/3A UBEC      │        │ — kill-switch inline on V+   │
└─────────────────┘        └──────────────────────────────┘

GND — tied together between both rails (mandatory common ground).
```

**Never** feed servos from the Pi 5V pin. Brown-out = CPU reboot mid-LLM-inference.

## I2C Bus (Pi ↔ PCA9685)

| PCA9685 pin | Pi GPIO pin | Pi BCM | Notes |
|---|---|---|---|
| VCC (logic)  | Pin 1 | 3V3 | Powers the PCA9685 logic side |
| GND | Pin 6 | — | Common ground |
| SDA | Pin 3 | GPIO2 | I2C data |
| SCL | Pin 5 | GPIO3 | I2C clock |
| V+ (servo) | (external 5–6V rail) | — | DO NOT connect to Pi |

Verify with `i2cdetect -y 1` — should show `40` in the grid.

## Servo Channel Map (PCA9685)

| Channel | Joint | Servo | Physical role |
|---|---|---|---|
| 0 | J1 — base_rotate | SG90 | Arm shoulder pivot relative to chassis |
| 1 | J2 — shoulder | SG90 | Lifts the upper arm |
| 2 | J3 — elbow | SG90 | Flexes the forearm |
| 3 | J4 — gripper | SG90 | Opens/closes gripper jaw |
| 4 | turntable | MG90S | Rotates the whole chassis |

Each servo has three wires: brown/black (GND), red (V+ from battery rail), orange/yellow (signal to PCA9685 channel).

## Kill Switch

SPST toggle wired inline on the **servo V+ line** (between battery + and PCA9685 V+). Cuts ALL servo power instantly without affecting the Pi. Test with a multimeter before first power-up.

## Camera

Pick one path; `dumme/vision/camera.py` supports both.

### USB UVC webcam (current build)

Plug into any Pi 5 USB-A port. The kernel exposes it as `/dev/video0`. No
`raspi-config` step needed. Verify:

```bash
lsusb                        # "UVC Camera" or "PC Camera" line appears
v4l2-ctl --list-devices      # shows /dev/video0
```

OpenCV opens it via `cv2.VideoCapture(0, cv2.CAP_V4L2)` — see `Camera._open`.

### CSI Pi Camera Module (alternative)

Ribbon → CSI port on Pi 5. **Blue tab faces the Ethernet port.** If reversed,
`picamera2` init fails. Swap `Camera._open` for a `picamera2.Picamera2()`
instance if you go this route; the rest of the vision stack is unchanged.

## Chassis Turntable

- MG90S mounted to the lower disc.
- Servo horn glued + screwed to the upper disc.
- Skewer/dowel through both disc centers as rotation axis.
- Low-friction washer between discs (plastic lid works).
- Cable loop through the center pin — leaves slack for rotation.

## Mechanical frame options

We started with a cardboard + hot-glue build for rapid iteration; it works
for the electronics but flexes under the arm's own weight and loses
positional accuracy at the elbow. If you're running this past the
hackathon, print the parts in `3d-models/sg90-robot-arm-model_files/`
instead — STL + 3MF ready for any slicer, Fusion 360 sources if you want
to re-mesh. The servo channel map and `config/servos.yaml` are identical
for both frames; only mechanical rigidity changes.

## Optional (stretch)

### Ultrasonic E-stop
HC-SR04 → Pi 5V + GND + GPIO trigger/echo. If reading <20 cm, app trips `EstopFlag`.

### USB Mic / Speaker
- Pi 5 has **no** 3.5mm audio jack. Use a USB sound card or USB speaker.
- Mic: any cheap USB mic works with Vosk.

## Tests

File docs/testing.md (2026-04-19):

# DummE — Testing, Verification, Evaluation

The test suite is sliced into **four tiers**, each with a pytest marker. The
default `pytest` run hits **unit + integration** only; `eval` and `hardware`
tiers are opt-in so a MacBook dev box stays green without a Gemma server
or a Pi attached.

| Marker | Runs by default? | What it needs |
|---|---|---|
| `unit` | yes | Nothing. Fully hermetic. |
| `integration` | yes | Nothing — FastAPI `TestClient` with a stubbed LLM. |
| `eval` | no | A reachable `llama-server` (defaults to `http://127.0.0.1:8080`). |
| `hardware` | no | A Pi with `/dev/i2c-1`, `/dev/video0`, and a live `llama-server`. |

Config lives in `pyproject.toml` under `[tool.pytest.ini_options]`:

```toml
markers = [
    "unit: fast isolated tests",
    "integration: require external services",
    "eval: hits the live llama-server; slow",
    "hardware: requires Pi + I2C + camera",
]
addopts = "-ra --strict-markers -m 'not eval and not hardware'"
```

## Running the suite

```bash
# Default: unit + integration.
pytest
make test

# Opt-in tiers.
pytest -m eval                       # LLM utterance parsing eval
pytest -m hardware                   # on the Pi only
pytest -m "unit or integration or eval or hardware"   # everything
make test-all

# Coverage (80% floor on `dumme/`, configured in pyproject).
pytest --cov=dumme --cov-report=term-missing
make coverage
```

## Tier 1 — unit tests

| File | Covers |
|---|---|
| `tests/test_calibration_fit.py` | Affine least-squares fit, pixel→polar, reach envelope |
| `tests/test_safety_limits.py` | Joint-limit clamp, `EstopFlag` thread-safety, `Safety.allowed` |
| `tests/test_llm_parser.py` | JSON extraction, `Command` coercion, `LLM.parse` retry/fallback |
| `tests/test_llm_client.py` | `LlamaClient.complete` POST shape, `healthy()` 200/500/refused |
| `tests/test_vision_detector.py` | Synthetic BGR frames, HSV hue-wrap (red), area threshold, largest-contour selection |
| `tests/test_motion_driver.py` | PCA9685 mock mode, channel bounds, release semantics |
| `tests/test_motion_primitives.py` | `home`, `rotate`, `pick`, `place`, `_us_for_angle`, e-stop refusal |
| `tests/test_orchestrator.py` | Command dispatch, sweep sequencing, target-not-found, crash-safety `release_all` |

## Tier 2 — integration

| File | Covers |
|---|---|
| `tests/test_app_endpoints.py` | FastAPI `TestClient` against the lifespan-built `Services` — `/status`, `/command`, `/estop`, `/estop/clear`, `/`. LLM is replaced post-startup with a canned `FakeLLM` so the path is deterministic without a live server. |

`DUMME_MOCK_HARDWARE=true` is set at import time to route all hardware
modules through mock implementations.

## Tier 3 — evaluation (`@pytest.mark.eval`)

**`tests/eval/test_utterance_parsing.py`** parametrizes the 20 canonical
utterances defined once in `scripts/prompt_test.py::CASES` and asserts each
parses to its expected `Command`. The module `pytest.skip`s cleanly when
the server isn't reachable.

**Eval report artifact** — `tests/eval/conftest.py` installs a
`pytest_sessionfinish` hook that writes `eval_report.json` at repo root:

```json
{
  "summary": {"total": 20, "passed": 19, "failed": 1, "accuracy": 0.95},
  "cases": [
    {"id": "test_utterance_parses_to_expected[00:'pick up the red block']", "outcome": "passed", "duration_s": 1.1},
    ...
  ]
}
```

Use this to diff accuracy across prompt edits. A drop is the signal that
`config/prompts/command_parser.txt` or the stop-tokens need tuning.

## Tier 4 — hardware smoke (`@pytest.mark.hardware`)

**`tests/hardware/test_hardware_smoke.py`** — skips cleanly if a
prerequisite is missing, fails loudly if it's present but misbehaving:

| Test | Prerequisite | Asserts |
|---|---|---|
| `test_pca9685_on_i2c_bus_1` | `/dev/i2c-1` + `smbus2` | MODE1 read at `0x40` doesn't `OSError` |
| `test_camera_captures_a_frame` | `/dev/video0` + `cv2` | `cv2.VideoCapture(0)` returns a non-uniform frame |
| `test_llama_server_health` | `LlamaClient().healthy()` | `/health` → 200 |
| `test_llama_server_roundtrip` | same | `complete()` returns non-empty string |

Run on the Pi: `pytest -m hardware`.

## `scripts/preflight.sh` — the 5-minute checklist

Run 5 minutes before demo. Self-contained bash; exits nonzero on first
failure. Checks (in order):

1. `curl /health` on `http://127.0.0.1:8080` (llama-server)
2. `curl /status` on `http://127.0.0.1:8000` (app)
3. `i2cdetect -y 1` shows `40` (PCA9685)
4. `/dev/video0` present (USB camera)
5. `cv2.VideoCapture(0).read()` returns a frame

```bash
make smoke            # equivalent to: bash scripts/preflight.sh
```

## CI (`.github/workflows/ci.yml`)

Triggered on pushes to `main` and every PR. Two jobs:

- **lint** — `ruff check`, `ruff format --check`, `black --check`
- **test** — `pip install -e ".[dev]"`, `pytest -v`, upload `coverage.xml`

`eval` and `hardware` tiers don't run in CI — default addopts skip them.

## Pre-commit

Install once per clone:

```bash
pip install pre-commit
pre-commit install
```

Hooks run on staged files: `ruff --fix`, `ruff format`, trailing-whitespace,
EOF fixer, YAML check, large-file guard (500 KB), merge-conflict marker.

## Coverage gate

`[tool.coverage.run]` sources `dumme/`, branch coverage on. `dumme/io/mic.py`
is omitted while Vosk STT is still a stretch.

`[tool.coverage.report]` has `fail_under = 80` — PRs that drop below 80%
fail the test job. Current floor is comfortable (≈ 84%); the uncovered
paths are real-hardware branches in `camera.py` and `tts.py` that land
under the `@hardware` tier, not the unit gate.

## What's NOT tested (and why)

| Gap | Why | Mitigation |
|---|---|---|
| Full kinematics of `Motion.pick` / `place` | `r_mm` is currently ignored (calibration regression placeholder). Only the pulse-width math is real. | Tests assert that the driver receives *some* write per joint — exact angles land when the real IK does. |
| MJPEG `/stream` endpoint | `TestClient` + sync-generator StreamingResponse deadlocks cleanup. | Covered by `Camera.mjpeg_frames` yield-one-frame behavior in the hardware tier. |
| `Mic.listen` (Vosk STT) | Still `NotImplementedError`; omitted from coverage. | `tests/test_mic.py` covers the mock-mode path only. |
| Real servo motion | Can't replicate a cardboard arm in CI. | `scripts/servo_sweep.py` is the manual smoke; `preflight.sh` is the sanity check. |

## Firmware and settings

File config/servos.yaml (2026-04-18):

# PCA9685 servo layout. Pulse widths are microseconds at 50 Hz.
# SG90 typical: 500–2500us → 0–180°. MG90S same range.
# home_deg is where each joint rests after `Motion.home()`.

servos:
  base_rotate:
    channel: 0          # J1 — rotates the arm shoulder relative to chassis
    min_us: 500
    max_us: 2500
    home_deg: 90
  shoulder:
    channel: 1          # J2
    min_us: 500
    max_us: 2500
    home_deg: 90
  elbow:
    channel: 2          # J3
    min_us: 500
    max_us: 2500
    home_deg: 90
  gripper:
    channel: 3          # J4 — open ~90°, close ~30°
    min_us: 500
    max_us: 2500
    home_deg: 60
  turntable:
    channel: 4          # MG90S — rotates the whole chassis
    min_us: 500
    max_us: 2500
    home_deg: 90

# Mechanical joint limits — never exceed, safety clamps before PWM write.
joint_limits:
  base_rotate: [0, 180]
  shoulder: [30, 150]
  elbow: [20, 160]
  gripper: [25, 95]
  turntable: [30, 150]

# Max angular velocity per joint. Slower = less torque spike = less SG90 jitter.
rate_limit_deg_per_sec: 90

# PWM frequency for the PCA9685. 50 Hz is standard for hobby servos.
pwm_frequency_hz: 50

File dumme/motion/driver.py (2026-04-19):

"""Thin wrapper over adafruit_pca9685 that exposes a per-channel microsecond API.

On non-Pi platforms (MacBook dev), the adafruit + busio imports will fail.
We defer them to __init__ so `import dumme.motion.driver` still works for
signature introspection, tests, and linting.
"""

from __future__ import annotations

from dumme.utils.logging import get_logger

_log = get_logger(__name__)


class PCA9685Driver:
    """Translate `(channel, pulse_us)` into 12-bit duty cycle writes on the PCA9685."""

    def __init__(
        self,
        pwm_frequency_hz: int = 50,
        i2c_address: int = 0x40,
        mock: bool = False,
    ) -> None:
        """If `mock=True`, stores writes in a dict for introspection — no I2C I/O."""
        self.pwm_frequency_hz = pwm_frequency_hz
        self.i2c_address = i2c_address
        self.mock = mock
        self._last_us: dict[int, float] = {}
        self._pca = None  # filled in by _connect() on real hardware

        if not mock:
            self._connect()

    def _connect(self) -> None:
        """Lazy-import adafruit so this module loads on non-Pi dev boxes."""
        import board
        import busio
        from adafruit_pca9685 import PCA9685

        i2c = busio.I2C(board.SCL, board.SDA)
        self._pca = PCA9685(i2c, address=self.i2c_address)
        self._pca.frequency = self.pwm_frequency_hz
        _log.info(
            "PCA9685 connected addr=0x%02x freq=%dHz", self.i2c_address, self.pwm_frequency_hz
        )

    def set_pulse_us(self, channel: int, pulse_us: float) -> None:
        """Write a pulse width in microseconds to `channel` (0-15)."""
        if not 0 <= channel <= 15:
            raise ValueError(f"channel must be 0..15, got {channel}")
        self._last_us[channel] = pulse_us
        if self.mock:
            _log.debug("mock PCA9685 ch=%d pulse_us=%.1f", channel, pulse_us)
            return
        period_us = 1_000_000.0 / self.pwm_frequency_hz
        duty = 0 if pulse_us <= 0 else int(max(0.0, min(1.0, pulse_us / period_us)) * 0xFFFF)
        self._pca.channels[channel].duty_cycle = duty

    def release(self, channel: int) -> None:
        """Zero PWM on `channel` — stops SG90 jitter at rest."""
        self.set_pulse_us(channel, 0.0)

    def release_all(self) -> None:
        for ch in range(16):
            self.release(ch)

    def last_written_us(self, channel: int) -> float | None:
        return self._last_us.get(channel)

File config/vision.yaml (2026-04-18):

# HSV color ranges for OpenCV (H: 0–179, S: 0–255, V: 0–255).
# Tuned under typical indoor lighting; re-tune with a desk lamp before demo.
# Red wraps around 0°, so two masks are OR'd together.

colors:
  red:
    ranges:
      - { h_low: 0,   s_low: 120, v_low: 70, h_high: 10,  s_high: 255, v_high: 255 }
      - { h_low: 170, s_low: 120, v_low: 70, h_high: 179, s_high: 255, v_high: 255 }
  blue:
    ranges:
      - { h_low: 100, s_low: 120, v_low: 70, h_high: 130, s_high: 255, v_high: 255 }
  green:
    ranges:
      - { h_low: 40,  s_low: 70,  v_low: 50, h_high: 80,  s_high: 255, v_high: 255 }

# Morphological filtering — removes specks, closes holes.
morphology:
  kernel_size: 5
  erode_iterations: 1
  dilate_iterations: 2

# Ignore contours smaller than this (noise rejection).
min_contour_area_px: 500

# Camera capture settings.
camera:
  width: 640
  height: 480
  framerate: 15
  # Fixed exposure helps HSV repeatability; set null for auto.
  exposure_us: null

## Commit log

2026-04-18 feat: initial commit
    [calibration.yaml, servos.yaml]
2026-04-19 feat: implement motion, vision, llm, and tts modules
    - PCA9685 driver + Motion primitives (home, base_rotate, turntable_rotate,
    pick, place) — verified on real hardware at I2C 0x40.
    - Camera: swap picamera2 stub for OpenCV V4L2 (USB webcam at /dev/video0)
    and implement HSV blob detector returning largest-contour centroid.
    - LLM: POST /completion to llama-server and parse JSON-strict output
    with one retry + graceful fallback to Command(unknown).
    - TTS: piper CLI + espeak-ng fallback with fire-and-forget error handling;
    wired into Orchestrator.on_status for demo narration.
    - .gitignore: exclude pi-passwords.txt.
    End-to-end tested on Pi 5 against Gemma 3n: "go home" completes in ~5s,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
    [driver.py, primitives.py]
2026-04-19 Tests, verification, eval, docs restructure + submission (#2)
    * test: tier 0 — eval harness + orchestrator tests + preflight
    - Register `eval` and `hardware` pytest markers; default run excludes both
    - tests/eval/test_utterance_parsing.py: parametrizes the 20 CASES from
    scripts/prompt_test.py, skips module when llama-server is unreachable
    - tests/test_orchestrator.py: FakeMotion/FakeVision/FakeCalibration cover
    home, unknown, happy-path pick_and_place, target-not-found, missing
    colors, out-of-reach, and the crash-safety release_all path
    - scripts/preflight.sh: 5 pre-demo smoke checks (llama-server, app,
    PCA9685, /dev/video0, cv2 capture)
    * test: tier 1 — unit coverage for every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
    [Goo-Base.3mf, GripperFul.3mf, sg90 full .3mf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]
2026-04-19 feat: add on-device voice commands via Vosk (#3)
    - dumme/io/mic.py: Mic class with sounddevice input + KaldiRecognizer,
    silence-bounded early exit, lazy model load, mock mode for dev boxes.
    - dumme/app.py: POST /listen route records, transcribes, and runs through
    the existing LLM + orchestrator pipeline.
    - static/: 🎤 Speak button in the browser UI, fills the text box with the
    transcript and displays the execution result.
    - tests/test_mic.py: 7 unit tests covering mock mode and the
    model-missing graceful-failure paths.
    [test_mic.py]
